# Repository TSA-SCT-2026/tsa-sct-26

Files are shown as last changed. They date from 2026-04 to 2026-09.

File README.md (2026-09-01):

# LEGO Brick Sorter

An ESP32-controlled conveyor that identifies red and blue 2x2 and 2x3 LEGO
bricks, then routes them into four bins with a servo-driven rotary chute. I
built the machine for the 2026 TSA System Control Technology event.

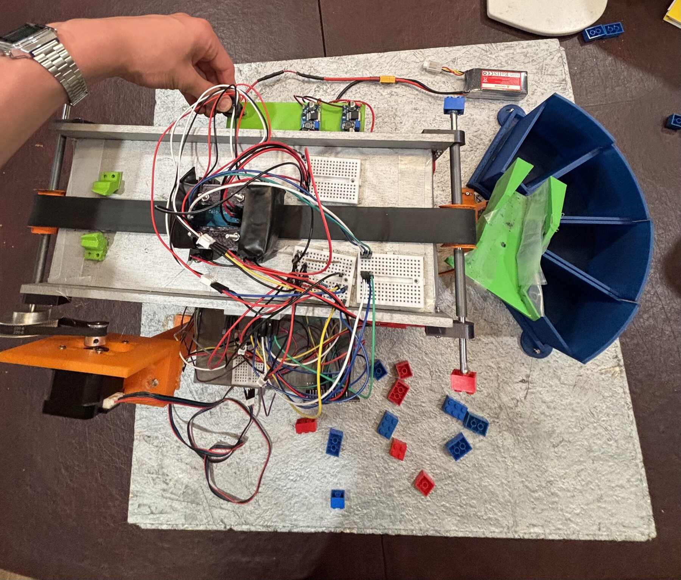
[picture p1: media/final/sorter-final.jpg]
Completed LEGO brick sorter with conveyor, sensing station, rotary chute, and four output bins


Over a roughly one-month, 200-hour development cycle, I worked across the
mechanical design and CAD, power and signal planning, fabrication, firmware,
calibration, and full-system debugging. At its fastest observed operating
point, the completed sorter processed approximately **0.3 bricks/second**, or
**18 bricks/minute**.

## Working demo

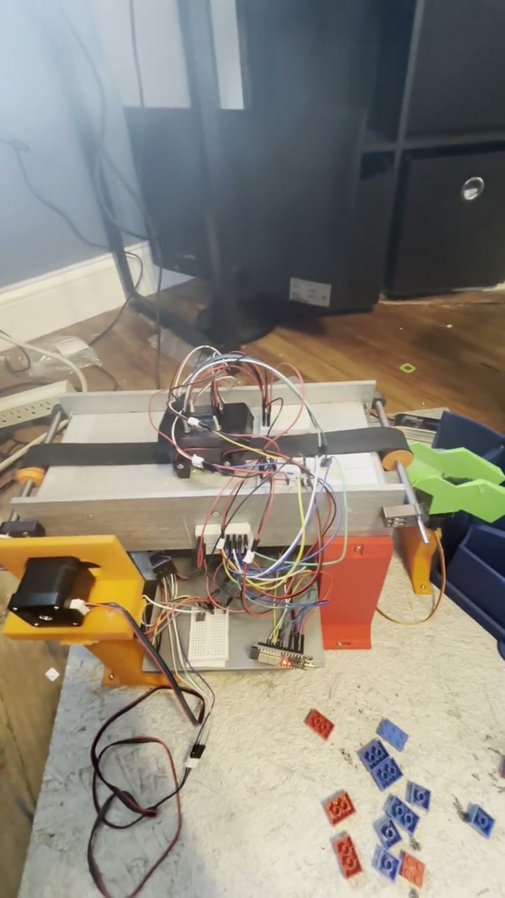
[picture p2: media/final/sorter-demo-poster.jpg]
Watch the completed LEGO brick sorter operate on YouTube


**[Watch the 32-second operating demo on YouTube](https://www.youtube.com/watch?v=zOtNFu6YxYQ).**
The video shows the final conveyor, sensor assembly, rotary chute, and four-bin
layout running as an integrated system.

## System at a glance

A NEMA17 motor drives each brick along the GT2 conveyor and through two break
beams. Between them, a shrouded TCS3200 sensor samples the brick's color. The
ESP32 combines the color reading with timing from the break beams to classify
the brick by size and color, then turns the servo-driven rotary chute toward
the corresponding bin.

- **Mechanics:** dimension-driven conveyor, adjustable sensor mounts, rotary
  chute, and four-bin collection arc
- **Electronics:** ESP32, TMC2209 stepper driver, two break beams, TCS3200 color
  sensor, high-torque servo, fused battery input, and separate voltage rails
- **Firmware:** interrupt-backed edge timing, moving color sampling,
  operator-assisted calibration, NVS persistence, and an event-driven state
  machine
- **Output classes:** 2x2 red, 2x3 red, 2x3 blue, and 2x2 blue

The controller processes one brick at a time across five states: `FEED`,
`SENSING`, `ROUTING`, `HANDOFF`, and `CONFIRM`. It commits the chute position
before the brick reaches the end of the belt.

## Engineering highlights

### Designing from physical constraints

The machine was designed as a connected chain of dimensions rather than a set
of independent parts. Starting with the brick envelope established the usable
belt width and sensing region. Those dimensions constrained the chute mouth and
sweep, which set the bin arc, conveyor height, and the remaining motor,
electronics, and support geometry. Adjustment slots at key interfaces gave the
physical build room for belt tension, print variation, and alignment.

The full dimensional reasoning and build sequence are documented in
[BUILD.md](BUILD.md#constraint-driven-mechanical-design).

### Measuring size as the belt moves

The two break beams are separated by $d = 40.436\ \text{mm}$. Instead of
classifying a brick from a fixed obstruction time, the firmware estimates belt
velocity from each brick's transit between the beams:

$$
v_{\text{lead}} = \frac{d}{t_{B,\text{in}} - t_{A,\text{in}}}
\qquad
v_{\text{trail}} = \frac{d}{t_{B,\text{out}} - t_{A,\text{out}}}
$$

When both estimates are valid, the firmware averages them and converts each
beam's blocked duration into a physical length:

$$
\bar{v} = \frac{v_{\text{lead}} + v_{\text{trail}}}{2}
\qquad
L_A = \bar{v}\left(t_{A,\text{out}} - t_{A,\text{in}}\right)
\qquad
L_B = \bar{v}\left(t_{B,\text{out}} - t_{B,\text{in}}\right)
$$

This keeps the size threshold tied to physical length even as belt tension,
friction, or motor speed changes. The firmware also compares $L_A$ and $L_B$
and handles incomplete or noisy edge sequences explicitly. See the
[full timing and fallback logic](ARCHITECTURE.md#size-measurement) or its
[`sensors.cpp` implementation](firmware/tsa_sorter/sensors.cpp).

### Separating brick color from the moving belt

The TCS3200 cycles through red, blue, and clear filters while a brick crosses
the sensing station. The firmware aggregates multiple samples, subtracts a
captured moving-belt baseline channel by channel, rejects low-signal readings,
and classifies the resulting red/blue relationship.

Calibration is operator-assisted: known bricks establish the working color and
size thresholds, and the selected values and belt baseline are saved in ESP32
NVS. This made it possible to recalibrate the machine without recompiling the
firmware.

### Integrating power, sensing, and control

I sketched the power distribution and signal paths before wiring the machine. A
fuse sits after the battery input, the stepper driver uses the higher-voltage
motor path, and buck conversion supplies the lower-voltage ESP32 and peripheral
rail. The control firmware combines interrupt-time sensor capture with a
64-entry event queue, scheduled chute motion, a single active brick record, and
safe output states for invalid routes or queue overflow.

The [electrical section in BUILD.md](BUILD.md#electrical) includes the original
planning sketches and current firmware pin map. The complete state flow and
failure behavior are in [ARCHITECTURE.md](ARCHITECTURE.md).

## From sketches to a working machine

The first two to three weeks focused on dimensional planning, component
selection, ordering, sketches, and CAD. Fabrication, electronics integration,
firmware, calibration, and debugging came together in a concentrated final
two-week build sprint.

| Frame and rollers | Belt curing and alignment | Electronics integration |
| --- | --- | --- |
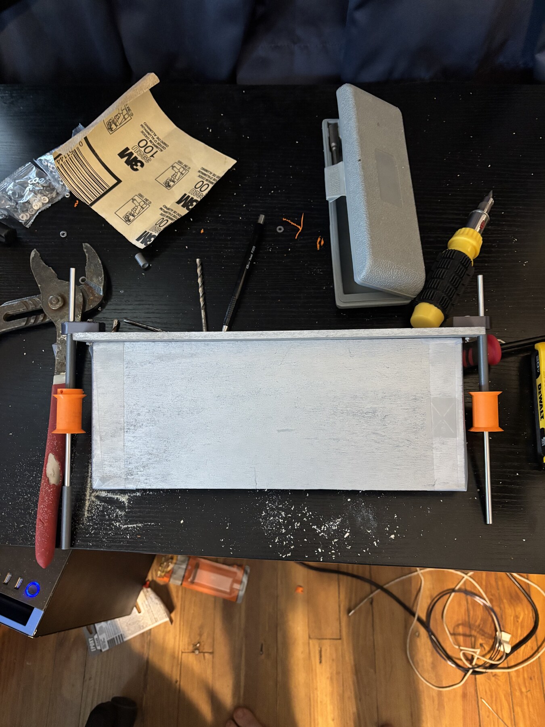
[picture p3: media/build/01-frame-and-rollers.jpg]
Wooden conveyor frame with printed rollers
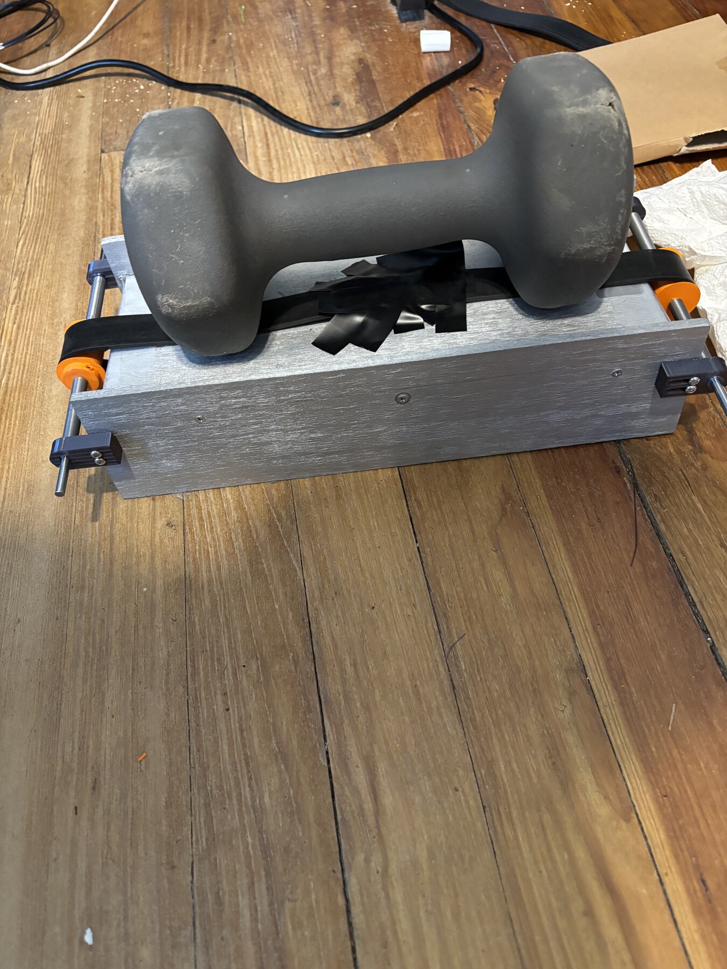
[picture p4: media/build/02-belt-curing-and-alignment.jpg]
Conveyor belt held under weight while epoxy cures
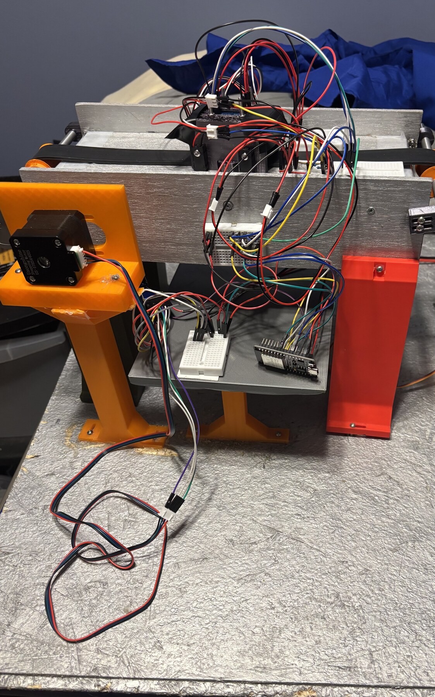
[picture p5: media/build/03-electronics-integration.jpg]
Sorter during electronics integration
|  |  |  |

[See the complete build, wiring, and calibration guide](BUILD.md).

## Explore the project

| Area | Start here |
| --- | --- |
| Firmware and calibration tools | [`firmware/`](firmware/) |
| Control flow and sensing math | [ARCHITECTURE.md](ARCHITECTURE.md) |
| Mechanical build and electrical planning | [BUILD.md](BUILD.md) |
| Conveyor CAD export | [`cad/exports/conveyor-assembly.step`](cad/exports/conveyor-assembly.step) |
| Active-system parts list | [`hardware/BOM.csv`](hardware/BOM.csv) |
| Component references | [`docs/datasheet/`](docs/datasheet/) |

The main firmware is organized by responsibility:

- [`sensors.cpp`](firmware/tsa_sorter/sensors.cpp) — beam timing, TCS3200
  sampling, classification, and calibration data
- [`state_machine.cpp`](firmware/tsa_sorter/state_machine.cpp) — sequential
  feed, sense, route, handoff, and confirmation flow
- [`actuators.cpp`](firmware/tsa_sorter/actuators.cpp) — conveyor profiles,
  servo positioning, and fail-safe outputs
- [`test_harness.cpp`](firmware/tsa_sorter/test_harness.cpp) — serial commands
  for calibration and component testing

## Project role

This was a team TSA project. I am Joe Roche, and I physically built the sorter
while working across its mechanical/CAD, electrical, firmware, calibration, and
integration work.

## License

This repository is available under the [MIT License](LICENSE).

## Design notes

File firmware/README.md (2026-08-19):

# Firmware

PlatformIO firmware for the ESP32-controlled LEGO brick sorter.

## Build

```sh
pio run
pio run -e servo_tuning
```

The default `esp32dev` environment builds `tsa_sorter/`. The
`servo_tuning` environment builds `tools/servo_tuning/main.cpp`.

## Flash and monitor

```sh
pio run -t upload
pio device monitor -b 115200
```

The serial harness supports component checks, human-readable or CSV logging,
operator-assisted calibration, speed-profile selection, and simulated events.
Run `help` in the monitor for the current command list.

Common calibration commands:

```text
cal show
cal belt 8
set color <ratio>
set size <millimeters>
cal save
```

`cal belt` captures a belt baseline. The operator must still choose the color
and size thresholds from physical-run evidence; the firmware does not derive
them automatically.

Use `tools/capture_serial_log.sh` to retain calibration or acceptance evidence.
See [BUILD.md](../BUILD.md) for the full procedure.

## Structure

- `tsa_sorter/`: production controller, sensing, routing, logging, and harness.
- `tools/servo_tuning/`: independent servo-position utility.
- `tools/capture_serial_log.sh`: serial log capture helper.

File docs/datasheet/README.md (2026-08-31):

# Retained Component References

This is a selective extract from the authentic pre-cleanup component library.
It is not a general vendor-download mirror. Each retained file supports a
specific final-system constraint.

| Reference | Constraint it informed |
| --- | --- |
| [`electrical/stepper_driver/images/wiring.png`](electrical/stepper_driver/images/wiring.png) | TMC2209 carrier pin orientation and MS1/MS2 microstep selection. Validate the installed carrier revision before wiring. |
| [`motion/nema17/images/schematic.png`](motion/nema17/images/schematic.png) | NEMA17 mounting pattern, 5 mm shaft, body/shaft envelope, and winding labels used for motor-mount and connector clearance. |
| [`motion/nema17/images/specs.png`](motion/nema17/images/specs.png) | 17HS4401 current, holding-torque, step-angle, and mass reference used to check driver and structure assumptions. |
| [`motion/nema17/cad/stepper_17hs4401s.step`](motion/nema17/cad/stepper_17hs4401s.step) | Reference envelope for the conveyor motor mount; it is supplier geometry, not project-authored CAD. |
| [`fasteners/bearing/cad/nsk_mr85zz.stp`](fasteners/bearing/cad/nsk_mr85zz.stp) | MR85ZZ bearing envelope used for shaft-support and pocket-fit checks. |
| [`reference/lego_2x3/lego2x3_red.stp`](reference/lego_2x3/lego2x3_red.stp) and [`reference/lego_2x3/lego2x3_red.txt`](reference/lego_2x3/lego2x3_red.txt) | Longest supported brick envelope used for guide, shroud, and chute clearance. |
| [`sensing/color_sensor/datasheets/gy31_color_module.pdf`](sensing/color_sensor/datasheets/gy31_color_module.pdf) | GY-31 module pinout, 2.7-5.5 V range, LED control, and 33.2 x 33.2 x 25 mm module envelope. |
| [`sensing/color_sensor/datasheets/tcs230.pdf`](sensing/color_sensor/datasheets/tcs230.pdf) | TCS230/TCS3200-family filter selection, output-frequency scaling, pulse-output behavior, and electrical limits behind firmware sampling. |

## Deliberate exclusions

- Generic product photos, branded
  belt/pulley vendor models are excluded because the system-level conveyor STEP
  already carries the useful assembled geometry. Other parts, such as the IR break beams, may require modifications to CAD depending on size. Cross check parts to order with CAD models.

These files remain third-party references. Their presence does not imply
project authorship or grant redistribution rights beyond their original terms.

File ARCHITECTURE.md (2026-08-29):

# Architecture

The sorter is a sequential, event-driven ESP32 system. It accepts one brick,
measures it inside a shrouded station, positions a rotary chute, and waits for
the timed handoff before accepting the next brick.

## Physical path

```text
feed guide
  -> GT2 conveyor
  -> beam A
  -> TCS3200 color sampling region
  -> beam B
  -> belt exit
  -> servo rotary chute
  -> four bins
```

The configured event set contains red and blue 2x2 and 2x3 bricks. Bricks are
fed studs up, with their long axis aligned to conveyor travel. The current
firmware owns one brick record at a time; physical spacing must prevent a second
brick from entering the sensing window before the controller returns to `FEED`.

## Firmware layers

| Area | Responsibility |
| --- | --- |
| `main.cpp` | Safe startup pin states, subsystem initialization, event dispatch |
| `sensors.cpp` | Interrupt-backed beam timing, color sampling, classification, calibration state |
| `state_machine.cpp` | Sequential feed, sense, route, handoff, confirm, complete, and error states |
| `actuators.cpp` | Stepper PWM, conveyor speed profiles, servo positioning, buzzer, status logging |
| `events.cpp` | Fixed-capacity event queue shared by hardware and the serial harness |
| `logger.cpp` | Human-readable and CSV serial evidence |
| `test_harness.cpp` | Serial commands for calibration, component checks, and simulated events |
| `tuning_profile.h` | ESP32 NVS persistence for operator-selected calibration values |

## State flow

```text
IDLE -> FEED -> SENSING -> ROUTING -> HANDOFF -> CONFIRM
          ^                                      |
          |                                      v
          +------------- next brick --------- FEED

COMPLETE is declared but is not reached automatically in the current path
on protected failure: ERROR_HALT
```

After a startup delay, the firmware starts a run automatically. There is no
physical start-button path in the current implementation. Beam A normally
opens the sensing cycle; beam B can provide a fallback entry trigger if beam A
is missed. Interrupt service routines retain the edge timestamps while the
64-entry event queue decouples input capture from state transitions.

## Size measurement

Let the active center-to-center beam spacing be $d$ (40.436 mm by default),
and define entry/exit timestamps from the active-low beam transitions. The
implemented estimates are:

$$
\Delta t_{lead}=t_{B,in}-t_{A,in},\quad
\Delta t_{trail}=t_{B,out}-t_{A,out}
$$

$$
v_{lead}=\frac{d}{\Delta t_{lead}},\quad
v_{trail}=\frac{d}{\Delta t_{trail}},\quad
v_{avg}=\frac{v_{lead}+v_{trail}}{2}
$$

When only a positive leading-edge delta is available, `v_avg` uses `v_lead`.
If no dynamic estimate is available, length calculation uses the configured
230 mm/s fallback. Beam occlusion durations
$\tau_A=t_{A,out}-t_{A,in}$ and
$\tau_B=t_{B,out}-t_{B,in}$ produce:

$$
L_A=v\tau_A,\qquad L_B=v\tau_B
$$

With both valid measurements, firmware averages the lengths when Beam A has at
most one extra edge, Beam B has at most two, and both speed and length skew are
at most 40%. Otherwise it prefers the beam with fewer extra transitions; on an
equal-edge high-skew result it conservatively chooses the larger length. A
single valid occlusion can supply a provisional length, but size classification
is marked valid only when Beam B entry and exit timing are complete. This keeps
the millimeter threshold responsive to measured belt motion while rejecting an
incomplete two-beam pass as a confident result.

## Color measurement

The TCS3200 is switched through red, blue, and clear filters during a pass. Each
filter frequency is derived from up to four valid pulse periods. During beam
transit the controller attempts a color sample every 70 ms; invalid pulse
periods are discarded. If the operator has captured a belt baseline, its
average red, blue, and clear frequencies are subtracted channel-by-channel and
clamped at zero before the sample is retained. The kept net channels are then
averaged across the pass and produce:

```text
red_ratio = red_net / (red_net + blue_net)
```

At least three belt-separated pass samples are required for a normal result.
Low-signal samples are rejected; if too few remain, the highest-signal rejected
sample is retained as an explicitly best-effort reading. The ratio is compared
with the operator-selected threshold. Current comments record repeated moving
known-brick clusters near 0.467 for blue and 0.512 for red, with a configured
0.490 threshold.

## Operator-assisted calibration

The software does not derive new thresholds automatically. An operator:

1. captures a belt baseline,
2. records representative red/blue and 2x2/2x3 passes,
3. chooses separating color and size thresholds,
4. enters those values over serial, and
5. saves the profile to NVS.

The saved profile contains the color threshold, size threshold, beam spacing,
and averaged belt readings. Defaults in `config.h` remain the recovery path.

## Routing and confirmation

The category-to-bin mapping selects one of four calibrated servo angles. The
controller estimates travel from the sensing station to the chute and tries to
position the chute before the brick commits to the exit. Conveyor speed can be
reduced when the available routing window is tight.

The current path is deliberately sequential: `_token` guards one active
`BrickRecord`, and the next record is created only after timed confirmation.
Events that do not match the current state are ignored; therefore the firmware
does not safely track a second physical brick entering the sensing window while
the first is routing. The serial `in_flight` diagnostic is retained for log
compatibility and is always `0`.

Confirmation is time-based. After the estimated handoff and confirmation
windows, firmware records the commanded bin; no per-bin sensor independently
confirms the landing.

## Active protection and failure behavior

- Startup clamps the active-low conveyor driver off before rail-settling delays.
- Servo and stepper PWM use isolated ESP32 timer/channel allocation.
- Event-queue overflow, an invalid servo route, or an internal token re-entry
  violation stops the conveyor, holds the selector, sounds the buzzer, logs the
  error, and enters `ERROR_HALT` until reset.
- Beam capture has a 3.5-second deadline. Incomplete timing becomes an uncertain
  result rather than an infinite wait; the state machine marks any forced route
  as low-confidence/guessed.
- Extra beam transitions plus speed/length skew determine whether two length
  estimates are averaged, one beam is preferred, or the larger estimate is
  used.
- Thresholds, pin assignments, timing constants, speed profiles, and servo
  angles are hardware-sensitive and should not change without a physical test.

Declared error names for feed timeout, sensor fault, position drift, and missed
bin remain in the interface, but the current physical path does not emit all of
them. Feed timeout presently logs and continues waiting, sensing retry is
compiled with a limit of zero, and no independent bin beam is installed.

## Implementation limits

- Status-display functions currently log over serial rather than driving a
  connected display.
- Timed confirmation records the commanded bin; it is not physical landing
  verification.
- `S_COMPLETE` exists, but the current confirmation path starts another brick
  instead of automatically ending after `TOTAL_BRICKS`; runs require operator
  control to stop at the intended set size.
- Low-confidence `chooseBestGuessBin()` routing currently maps 2x3 red to bin 4
  and 2x2 blue to bin 2; the normal confident category mapping is correct.
- The repository includes the pre-build wiring sketches and firmware pin map,
  but not a full as-built wiring schematic.

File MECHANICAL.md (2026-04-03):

# Mechanical Design Architecture

## Brick dimensions (source of truth)

| Brick | Length | Width | Height | Count | Colors |
|---|---|---|---|---|---|
| 2x2 | 15.8mm | 15.8mm | 11.4mm | 12 | 6 red, 6 blue |
| 2x3 | 23.7mm | 15.8mm | 11.4mm | 12 | 4 red, 8 blue |

Both bricks share the same width and height. Only length differs by 7.9mm. This single fact drives most mechanical and sensor decisions in the project.

## Physical constants

```
Belt width:              25mm
Belt type:               GT2 closed loop, 400mm, 6mm wide
Pulley teeth:            20
Pulley pitch diameter:   12.73mm (20 * 2mm pitch / pi)
Pulley center-to-center: 180mm
Belt speed (operating):  200mm/s
Brick spacing:           28mm center-to-center (23.7mm brick + 4.3mm buffer)
Feed rate:               5 bricks per second
Total sort time:         ~10 seconds for 24 bricks
Footprint:               610mm x 610mm
Materials:               3D printed PLA for all structural parts, fasteners and electronics excepted
```

Belt length math:
```
GT2 20-tooth pulley pitch diameter = 12.73mm
Belt wrap contribution = pi * 12.73 = 39.96mm, rounds to 40mm
400mm belt -> center distance = (400 - 40) / 2 = 180mm
```

System belt usage:
```
Chute base transition:       50mm
Taper channel:               60mm
Sensing zone:                30mm
Sensor to first plow buffer: 30mm
3 plows at ~28mm each:       84mm
Last plow to belt end:       20mm
Total belt needed:           274mm
Belt usable top run:         ~360mm
Margin:                      ~86mm
```

## Parts to print (in order)

1. Chute transition piece -- print and test first, before anything else
2. Stepper cam disk -- simple geometry, early iteration is cheap
3. Sensor shroud for color sensor -- needed for calibration validation
4. Everything else once the chute transition is proven

Do not print the full frame until the chute transition piece reliably feeds bricks at belt speed. That piece is the gate for the entire mechanical build.

## Gravity chute

Near-vertical stack angle: ~75 degrees from horizontal. Bricks orient studs-up for low contact area and minimal friction. Gravity feeds them down into the escapement.

```
Chute inner width:  17.3mm (15.8mm brick + 1.5mm clearance)
Stack height (all 2x3): 24 * 11.4mm = 273mm
Realistic mixed stack:  ~240mm
```

The inner profile must be rectangular to maintain brick orientation. Round pipe cannot constrain rotation -- PVC pipe is not a viable substitute. Aluminum square tube would be dimensionally more accurate than printed PLA but adds sourcing complexity and is harder to integrate with the printed frame. Printed PLA is the correct choice with proper tolerance allowance.

A brick loaded sideways jams at the chute entrance rather than deep in the system. This is the correct failure mode -- visible, immediate, and recoverable.

### Chute transition piece (highest risk item in the project)

The transition from near-vertical to horizontal at the chute base is a compound geometry problem. FDM tolerances bite hard on curved internal profiles. This piece must:
- Redirect bricks smoothly from ~75 degrees to horizontal
- Not allow bricks to tumble, jam, or stack at the curve
- Work reliably at the escapement release rate with bricks of both lengths

Print this first. Test with real bricks. Iterate until it works every time. Budget 3 iterations minimum. Do not proceed to full frame CAD until this passes. If this piece cannot be made to work reliably, the entire near-vertical chute concept needs revision before anything else is built.

## Stepper cam escapement

Single-lobe cam disk mounted on the stepper motor shaft. One full rotation releases exactly one brick and blocks the queue for the remainder of the rotation. This is mechanically guaranteed -- it cannot release a partial brick.

```
Approximate lobe dimensions: 12mm height, 15mm width
One full rotation = 200 steps (1.8 degrees per step)
Release portion = ~50 steps (90 degrees)
At target speed: 30ms per release
```

The cam disk geometry does not require a reference CAD model. A single-lobe disk is trivial to draw from these dimensions -- a circle with one raised protrusion. The lobe pushes the bottom brick onto the belt as it passes; the rest of the disk holds the queue. Iterate the lobe profile with real bricks if the first print does not push cleanly.

The stepper holds its position electrically between releases using reduced current. This means the queue cannot backdrive the escapement when the motor is stationary.

## Taper channel

```
Entrance width: 30mm
Exit width:     17.3mm
Taper length:   60mm
Position:       between chute exit and sensing zone
```

Forces bricks square before sensors and plows. A severely yawed brick jams here, not at the plow. Better failure mode.

## Sensing zone

```
Total zone length:     ~30mm
IR break-beam spacing: 19mm (along travel axis)
Color sensor standoff: 5-10mm above belt surface
```

The color sensor shroud is part of the channel roof geometry -- print it as one piece with the channel. Ambient light is the primary failure mode for the color sensor. The shroud must block all light except the sensor's integrated LED.

### Shroud design requirements

The shroud is not just a box around the sensor. It needs to:

1. Seal against the belt surface (or come very close) on the leading and trailing edges so ambient light cannot enter from the direction of travel. A gap of even 2-3mm at the belt surface at this standoff distance leaks enough light to shift color readings.
2. Allow bricks to enter and exit freely without snagging. The opening should be wider than the brick but use a labyrinth or overlapping lip geometry to block direct light paths rather than a simple open slot.
3. Have a flat ceiling at a consistent standoff distance (5-10mm). Variation in standoff distance across the brick changes the integrated light level and potentially the ratio. Consistent geometry matters.
4. Be CAD'd with the color sensor dimensions in mind -- mount the sensor board flush against the shroud ceiling, not floating inside it.

This piece needs to be iterated. Print it early, test it with a handheld flashlight pointed at the belt from various angles while the sensor is logging readings. If the ratio shifts when ambient light changes, the shroud is not tight enough.

### Brick orientation enforcement at chute entrance

The chute width (17.3mm) already prevents 2x3 bricks from entering rotated 90 degrees -- 23.7mm does not fit in 17.3mm. A 2x2 is square so rotation does not matter for it. Studs up vs studs down does not affect size or color measurements.

The remaining risk is a brick loaded completely on its side (11.4mm height presenting instead of 15.8mm length). Make the chute entrance opening narrow enough in the vertical dimension to prevent this. If a brick cannot enter on its side at the top of the chute, this failure mode is eliminated before it can cause a jam or misclassification.

## Plow diverters

Three plows, Class 3 lever geometry, solenoid actuated, spring return.

Lever geometry:
```
Pivot to solenoid attachment: 8mm (L1)
Pivot to plow tip:            24mm (L2)
Mechanical advantage ratio:   3.0
Solenoid stroke:              10mm
Tip travel:                   30mm (adequate to clear 15.8mm brick width on 25mm belt)
```

Tip travel needed calculation:
```
(belt width / 2) + (brick width / 2) + buffer = 12.5 + 7.9 + 4 = 24.4mm -> use 30mm
```

The solenoid connects to the lever arm via a pinned connection (M2 pin through a drilled hole or small clevis). Not a hook or slot -- a pinned connection eliminates rattle, wear, and angular play at speed.

A slot in the channel wall accommodates the arc the solenoid rod travels. At these angles the arc is nearly linear -- this is not a fabrication problem.

Chamfer the leading face of each plow arm at 35 degrees. Slightly yawed bricks get nudged square rather than jamming against the face.

### Plow spacing along belt

```
Footprint per plow along belt: ~32mm (lever length + 8mm safety gap)
3 plows total:                 ~96mm
```

### Spring selection

The force margin is large (~94x what the spring requires to return the arm). Use the heaviest spring from the assortment that the solenoid can still reliably overcome -- heavier spring means faster retraction, which is the optimization target. Test with the actual solenoid at operating voltage before committing to a spring weight.

## Bin design

Four bins, one per brick type. Bricks arrive at 200mm/s and will bounce out of empty bins without some form of energy absorption.

Options: foam sheet glued to bin floor, felt lining, or a short downward ramp printed into the bin geometry that redirects kinetic energy downward rather than back toward the belt. The ramp approach is preferable because it is zero-cost (print it into the bin), durable, and does not require gluing or sourcing foam in the right thickness.

## Fastener conventions

- Structural frame joints: M3
- Lever arm pin connections: M2
- Sensor and electronics mounts: M3 preferred
- Pre-order both M2 and M3 hardware kits

## Print tolerances

FDM variance is roughly 0.2mm to 0.5mm. All critical dimensions need explicit tolerance notes in CAD:

- Belt channel width (25mm): ±0.3mm acceptable
- Chute inner width (17.3mm): ±0.2mm, tighter is better, too tight and bricks drag
- Pulley center distance (180mm): tensioner slot provides 5mm of adjustment
- Plow lever arm lengths: ±0.5mm acceptable, ratio is what matters not absolute

Test fit all printed channel sections with real bricks before assembling the full frame.

## Assembly order

1. Chute transition piece validated in isolation
2. Full frame with all channel sections
3. Dry assembly: no wiring, walk a brick through by hand from chute to belt end
4. Fix all print fit issues before wiring anything
5. Wiring and electronics integration
6. First powered test

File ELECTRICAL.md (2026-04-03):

# Electrical Design Architecture

## Power architecture

Two independent power rails from a single 2S LiPo (7.4V, 2000mAh minimum), each stepped down to 5V via a dedicated buck converter.

```
Rail 1: solenoids only (high current, noisy switching)
Rail 2: stepper motor, belt motor, microcontroller, sensors, display (clean logic rail)
Common ground between rails -- only the ground is shared
```

Separating rails keeps solenoid switching noise off the logic rail and stepper driver switching noise off the solenoid rail. Both are real failure modes on a shared rail at this current draw.

### Power budget

```
3 plow solenoids (peak simultaneous): 3 * 500mA = 1500mA
Stepper motor:                        ~400mA
Belt motor:                           ~400mA
Microcontroller:                      ~250mA
Sensors and display:                  ~150mA
Total worst case:                     ~2700mA
Realistic operating peak:             ~1500mA
```

A USB power bank will not work. Most cut out at 1A or less under pulse load. Use LiPo.

Bench supply is acceptable for early development but must not be used for any calibration run that will be logged as performance data, and must not be used for the final demo. Test on LiPo before April 20.

## Component list and electrical specs

| Part | Purpose | Voltage | Peak current |
|---|---|---|---|
| JF-0530B solenoid (x3) | plow actuation | 5V | ~500mA each |
| NEMA 11 stepper motor | escapement | 6-8V (motor rail) | ~400mA |
| A4988 stepper driver | stepper control | motor rail + 3.3V logic | -- |
| TT gearmotor (x2, one spare) | belt drive | 5V | ~400mA |
| L298N motor driver | belt motor control | 5V | -- |
| LM2596 buck converter (x2) | 7.4V -> 5V | -- | 3A each rated |
| ESP32 DevKit | microcontroller | 3.3V (via onboard reg) | ~250mA |
| Adafruit IR break-beam pairs (x6 used) | size and bin sensing | 3.3-5V | low |
| TCS34725 color sensor | color classification | 3.3V | low |
| ST7789 color TFT display | live status display | 3.3V | ~80mA |
| H206 slot optocoupler | belt speed encoder | 3.3-5V | low |
| 2S LiPo 7.4V 2000mAh | main power source | 7.4V nominal | 2A continuous |

## Critical protection components

These are not optional. Skipping any of them risks destroying hardware.

### Capacitor on stepper driver motor power input

A 100uF electrolytic capacitor must be placed physically adjacent to the motor power input on the A4988 driver module. This is the single most common way the A4988 is destroyed -- back-EMF from the motor travels back up the power line on power connect. Without this capacitor, the chip dies. Place it right next to the chip, not at the power connector.

Before applying power to the stepper circuit for the first time: verify this capacitor is present and correctly oriented (negative leg to ground) with a teammate watching. Say it out loud.

### Flyback diodes on all solenoids

Every solenoid must have a flyback diode across its terminals. When the solenoid de-energizes, the collapsing magnetic field generates a large voltage spike. Without a flyback diode, this spike travels back into the microcontroller and will cause brownouts or permanent damage. 1N4007 diodes are sufficient.

Orientation: cathode (banded end) toward the positive supply rail, anode toward the solenoid terminal. A reversed diode is a short circuit.

Verify all three diodes with a multimeter before first solenoid energization.

### Pullup resistors on I2C lines

If the color sensor drops reads during high-speed polling, add 4.7k resistors from SDA and SCL to 3.3V. This is a diagnostic step, not mandatory upfront, but have the resistors available.

## Stepper driver wiring

```
A4988 VMOT + GND  -> motor rail (6-8V from LM2596)
A4988 VDD + GND   -> microcontroller 3.3V, shared ground
A4988 STEP        -> microcontroller GPIO
A4988 DIR         -> microcontroller GPIO (set once at startup)
A4988 SLEEP       -> pull HIGH (enables the driver)
A4988 RESET       -> tie to SLEEP pin
A4988 MS1/MS2/MS3 -> all LOW (full step mode, maximum torque)
A4988 coil pairs  -> NEMA 11 stepper coil wires (check datasheet for coil grouping)
```

VMOT should be 6-8V for the NEMA 11. Do not run from 5V -- insufficient torque at speed. Use the dedicated motor rail from Rail 2.

Between releases, reduce hold current via the driver's reference voltage trim. Sufficient torque to hold against queue pressure, much lower heat. This is done once during setup, not dynamically during normal operation.

## Belt motor wiring

Belt motor connects through the L298N module. The L298N enable pins accept PWM for speed control -- this is how the PI controller adjusts belt speed. No separate speed controller module is needed.

L298N PWM frequency: keep between 1kHz and 10kHz. Below 1kHz the motor audibly ticks. Above 25kHz the L298N's internal circuitry generates excessive heat and switching losses become significant. 5kHz is a reliable starting point.

Motor direction should be wired to run belt surface in the correct direction. Verify this before installing sensors or plows by running a brick manually.

## Bulk capacitor on logic rail

Add a 1000uF electrolytic capacitor between 5V and GND on the logic rail, physically close to the microcontroller. When solenoids fire on Rail 1, even with rail isolation, transients can couple through the common ground. The bulk cap buffers the logic supply during these events and prevents brief undervoltage that could cause a reset.

This is separate from the 100uF cap on the A4988 motor power input -- that one is for the stepper driver, this one is for the microcontroller supply. Both are needed.

## Solenoid control

Each solenoid connects to a microcontroller GPIO through a driver transistor or the L298N. Flyback diode across each solenoid (see above).

Solenoid timing pattern per brick:
- Full power for 15-20ms (full extension)
- Drop to ~40% duty cycle PWM for the remaining hold time (maintains position, roughly half the heat)
- De-energize once the brick has cleared the plow

Brick clears the plow roughly 280ms after the trigger (calculated from brick length, plow footprint, and belt speed). This is the de-energize point. It can be implemented as a fixed timer.

Add a small aluminum heatsink (20x20mm) to each solenoid body using thermal adhesive tape. This is cheap insurance against heat during extended calibration sessions, which will run more solenoid cycles than the competition demo.

## Sensor wiring

### IR break-beams

Each break-beam pair has an emitter and a receiver. The receiver output is a digital signal -- high when beam is intact, low when broken. Wire receivers to microcontroller GPIO pins configured as inputs. The emitter connects to 5V (check Adafruit datasheet for exact supply).

Two pairs for size detection in the sensing zone. One pair per bin entrance, four pairs total for confirmation. Six pairs used, two spare.

### Color sensor

Connects to the microcontroller over I2C. Set the I2C bus clock to 400kHz explicitly in firmware. The default 100kHz is insufficient for the rapid polling rate needed during brick dwell time.

### Display

Connects to the microcontroller over SPI. Runs at 40MHz SPI clock -- verify this is within the display panel's spec (ST7789 supports it). Power at 3.3V.

### Belt speed encoder (if using slotted disk option)

A photointerrupter (H206 or equivalent slot optocoupler) mounts next to the belt pulley. Its output is a digital pulse train -- one pulse per slot as the disk rotates. Wire the output to a GPIO interrupt pin on the microcontroller. Use the ESP32's hardware pulse counter peripheral for counting rather than software interrupts -- it handles high pulse rates without CPU overhead.

The disk can be printed directly into the belt pulley face (add 20 evenly spaced slots around the perimeter). No separate part needed.

## Wiring checklist before first power-on

- [ ] 100uF capacitor adjacent to A4988 motor power input, correctly oriented
- [ ] 1000uF capacitor on logic rail 5V supply, close to microcontroller
- [ ] All three solenoid flyback diodes installed, orientation verified with multimeter
- [ ] Rail 1 and Rail 2 separated, common ground only
- [ ] Both LM2596 outputs measured at 5V before connecting anything
- [ ] Stepper SLEEP pulled HIGH
- [ ] RESET tied to SLEEP
- [ ] Microcontroller powered from clean rail, not motor rail
- [ ] All I2C devices on same bus with shared SDA, SCL, and ground
- [ ] Display SPI connections correct (MOSI, SCLK, CS, DC, RST)
- [ ] Photointerrupter output connected to GPIO interrupt pin (if using slotted disk encoder)

## Common failure modes

| Failure | Cause | Prevention |
|---|---|---|
| A4988 destroyed on power-on | Missing or misplaced 100uF cap | Verify cap before power |
| Microcontroller brownout | Solenoid back-EMF, no flyback diode | Install all flyback diodes |
| Microcontroller brownout | Bench supply current limiting | Test on LiPo |
| Color sensor dropped reads | I2C too slow or noise | Set 400kHz, add pullups if needed |
| Solenoid overheating | Full power hold, no PWM | Implement PWM hold in firmware |
| Belt slipping | Loose belt from print tolerance | Use tensioner slot, re-tension |
| Stepper skipping steps | Insufficient VMOT voltage | Use dedicated motor rail at 6-8V |

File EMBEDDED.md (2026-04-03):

# Embedded Design Architecture

## State machine

```
IDLE -> FEEDING -> SIZE_DETECT -> COLOR_DETECT -> ROUTING -> CONFIRM -> FEEDING
                                                                  |
                                                             ERROR_HALT
```

- IDLE: ready screen on display, button waiting, thermal model cooling down between runs
- FEEDING: stepper fires one full rotation, one brick released onto belt
- SIZE_DETECT: hardware timer running, waiting for second beam break or timeout
- COLOR_DETECT: color sensor averaging samples over brick dwell time
- ROUTING: correct plow fires (or does not fire for default path), display animation triggers
- CONFIRM: waiting for the expected bin beam to break within 500ms
- ERROR_HALT: belt stops, stepper stops, all solenoids de-energize, display shows error with bin and brick number, system waits for reset

Transitions happen on hardware interrupt or timer expiry, not polling loops. The only exception is color sampling during COLOR_DETECT, which samples on a tight loop during the brick's dwell window.

## Size detection

Two IR break-beam pairs in the sensing zone, 19mm apart along the belt axis.

Use hardware timer interrupts -- not software polling, not delay-based measurement. The timer must have at least 1 microsecond resolution. This gives thousands of counts of margin on the 21ms signal window, making misclassification effectively impossible from timing alone.

```
Beam 1 breaks:                timer starts
Beam 2 breaks within timeout: brick is 2x3 (23.7mm long)
Beam 2 times out:             brick is 2x2 (15.8mm long)
```

How the geometry works:
- Beams are 19mm apart. Belt moves at 200mm/s.
- A 2x2 brick is 15.8mm long -- shorter than the 19mm beam gap. Its trailing edge clears beam 1 before its leading edge reaches beam 2. Beam 2 never breaks.
- A 2x3 brick is 23.7mm long -- longer than the gap. Its leading edge reaches beam 2 while the brick is still in beam 1. Time from beam 1 break to beam 2 break: 19mm / 200mm/s = 95ms.
- Timeout should be set above 95ms (use ~150ms). The classification threshold sits anywhere between 0 and 95ms -- 50ms is a reasonable starting point. Validate empirically at actual belt speed during calibration. The margin is large enough that the exact value does not matter much.

## Color detection

Color sensor faces down from the channel roof through a printed shroud, 5-10mm above the belt surface.

I2C bus must be explicitly configured to 400kHz. The default 100kHz is insufficient for the polling rate needed. Set this in initialization code before any sensor communication.

```
Brick dwell time at 200mm/s over 15.8mm: 79ms
Minimum integration time per sample: 2.4ms
Maximum samples per brick: 79 / 2.4 = ~32 samples
```

### Black belt filter

The GT2 belt is black rubber. When the sensor reads bare belt (between bricks, or at brick edges), total raw light across all channels is near zero. Black is trivially easy to detect: if the sum of all raw channels is below a floor threshold, discard the sample.

Set the floor threshold during calibration by logging raw totals for bare belt and brick surface separately. The gap between them will be obvious. This single filter cleanly handles all belt readings without any timing-based windowing logic.

Beam 1 windowing (gate sampling on beam break/restore) can be added as a secondary layer but should not be the primary mechanism. The black filter is simpler and more robust.

### Classification

Average all valid samples within the window. Classify using R / (R + G + B) ratio. Red LEGO bricks have a strong spectral signature and will produce a clearly high ratio. Blue LEGO bricks will produce a clearly low ratio. The gap between them is large -- this is one of the easier color classification problems you can choose. The risk is not in the classification math, it is in the windowing and shroud (see MECHANICAL.md for shroud design notes).

The exact threshold (nominally ~0.45) must be calibrated empirically with the shroud installed, demo bricks, belt running, integrated LED as the only light source. Log raw R/G/B values for both brick colors during calibration to understand the actual separation. Do not assume any threshold value.

### Tuning methodology

During calibration, run both brick colors at multiple belt speeds and log raw channel values for each sample. Determine:
- The actual ratio distributions for red vs blue at your operating speed
- The optimal threshold (midpoint between distributions, or weighted toward the more common misclassification direction)
- The minimum number of samples needed for reliable classification

This produces documentation data and a principled threshold choice.

## Routing logic

Routing is a direct lookup from classification result to plow assignment. Optimized by brick frequency so the most common brick type fires no solenoid.

```
2x3 blue (8/24): no solenoid fires -- default path, brick reaches end bin
2x2 blue (6/24): plow 1 fires
2x2 red  (6/24): plow 2 fires
2x3 red  (4/24): plow 3 fires
```

One plow fires per brick, maximum. Total solenoid fires per full run: 16.

Solenoid fires immediately when classification completes. The brick is still traveling from the sensing zone to the first plow -- roughly 150ms of travel time at 200mm/s over 30mm. Solenoid actuation takes 10ms. The plow is pre-set before the brick arrives.

PWM hold timing per solenoid:
- Full power for the first 20ms (full extension reached)
- Drop to ~40% PWM duty cycle (maintains position, reduced heat)
- De-energize at approximately 280ms after trigger (brick has cleared the plow)

This is implemented as a timer-based state transition in firmware. The de-energize time can be calculated at the start of each routing event.

## Bin confirmation

Four break-beams, one at each bin entrance. After a brick is routed, start a 500ms countdown for the expected bin beam.

On beam break within window: log success, increment bin counter, trigger display update, transition back to FEEDING.
On timeout: transition to ERROR_HALT.

GPIO interrupt priority: size detection beams are highest priority. Bin confirmation beams are lower priority. Do not allow a bin confirmation interrupt to delay a size detection measurement.

## Thermal model

Runs continuously. Tracks accumulated heat for each actuator independently. Heat increases when an actuator fires. Heat decays exponentially over time when idle.

```
On actuator fire:    heat += duration * heat_per_unit_time
Each update cycle:   heat *= cooling_factor ^ elapsed_seconds
```

Two thresholds:
- WARNING: reduce stepper release rate slightly (increase gap between bricks)
- DANGER: reduce stepper release rate significantly

The model protects hardware during back-to-back demo runs, not just a single run. Between runs, while in IDLE, the model continues to update and heat values decay. The display shows the thermal state as a small bar throughout.

Apply the model to all solenoids and the stepper motor. The belt motor does not need it.

## Belt speed control (PI controller)

Belt speed is a tunable parameter. Optimal speed balances throughput against classification accuracy. Too fast: color samples compress, size timing margins shrink, bricks may jam the taper. Too slow: run takes longer than needed.

### Three speed measurement options

**Option A: Reuse size detection break-beams (no extra hardware)**
- 2x3 bricks: time from beam 1 to beam 2 break = 19mm / speed
- 2x2 bricks: duration beam 1 is blocked = 15.8mm / speed
- Every brick gives a speed sample (~5 per second)
- Update rate is limited but workable for a slow process variable like belt speed

**Option B: Bin confirmation transit time (no extra hardware, already happening)**
- When a brick is routed, log the timestamp. When the bin confirmation beam breaks, log another.
- Speed = known sensor-to-bin distance / elapsed time
- Every brick gives a speed measurement, all 24 bricks per run
- Downside: measurement is trailing -- informs the next brick, not the current one
- Each bin is at a different distance from the sensor zone, so you need exact CAD measurements for all 4 paths (determine in dry assembly, not estimated)

**Option C: Slotted disk on belt pulley with photointerrupter (recommended, ~$1 extra)**
A printed disk with radial slots mounts on the belt pulley shaft. A U-shaped light sensor (photointerrupter/optocoupler) straddles the disk edge. As the pulley spins, slots pass through the sensor gap and generate pulses. Count pulses per unit time = rotation speed = belt speed.

At 200mm/s: pulley does ~5 rotations/sec. A 20-slot disk gives 100 pulses/sec -- one pulse every 10ms. This is continuous real-time feedback at high bandwidth, genuinely good for a PI controller. The disk can be printed directly as an extension of the belt pulley face. Requires adding one H206 slot sensor to the BOM (~$1).

This is the cleanest option. Use A or B for validation and logging. Use C for the actual PI controller if added.

### Tuning methodology

Run the full 24-brick set at multiple belt speeds (e.g., 100, 150, 200, 250mm/s). Log all per-brick classification results and confirmation outcomes. Identify:
- Minimum speed for reliable color classification
- Maximum speed before size detection degrades
- The accuracy vs speed curve

Set operational setpoint to the fastest speed that holds target accuracy (95%+). This generates strong documentation data and a principled, equation-backed design choice.

### PI controller notes

Start with proportional control only. Add integral if steady-state offset persists. Derivative not needed -- belt speed is slow and smooth. Gains will be small. The controller update rate is determined by whichever speed measurement option you use.

### Development tool: web server logging

The ESP32 has WiFi. During calibration and tuning, run a lightweight HTTP server that serves a live JSON feed of brick events, speed measurements, and classification results. Connect a laptop to the same network and log directly in the browser or with a simple script. This is faster and more convenient than serial + CSV piping for iterative tuning sessions. Disable or make it optional in competition firmware (adds latency).

## Display

Color TFT over SPI. All display updates happen asynchronously relative to the sensing and routing pipeline -- they must not block or delay state transitions.

During sort (triggered on ROUTING state entry, not on physical bin arrival):
- Brick silhouette animates down the chute graphic in the correct classification color (red or blue) and correct aspect ratio (2x2 or 2x3)
- Bin counter for the target bin flashes then increments
- Sidebar shows brick number, size, color, destination bin
- Thermal bar updates

Render bricks as small pre-rendered bitmaps stored in flash memory. Clear the background rectangle, redraw the bitmap -- no full-screen refresh needed. Animation should complete within 150ms to avoid queuing at 5 bricks per second.

RGB565 color format: red is 0xF800, blue is 0x001F. These are exact matches for LEGO red and blue under normal conditions.

End screen (triggered when all 24 bricks confirmed):
- SORT COMPLETE header
- Total run time
- Per-bin totals vs expected (6, 6, 4, 8)
- Count of missed confirmations if any
- Green indicator if all counts match, yellow if discrepancy

## Serial output

Log every event with a millisecond timestamp:
- Each brick: number, size classification, color classification, destination bin
- Each bin confirmation: timestamp, which bin, success or timeout
- End of run: all totals, total time
- Thermal model state periodically

Serial output is the engineering notebook. Pipe it to a laptop during calibration and save to CSV. Performance test data, belt speed validation (compare expected vs measured transit times), and accuracy rates all come from this log. Do not manually record runs.

The time between ROUTING timestamp and CONFIRM timestamp gives measured transit time, which divided into the sensor-to-bin distance gives measured belt speed. This is a sanity check on the belt speed calculation. Log it. Judges appreciate a system that validates its own performance claims.

## Button and start/stop

Momentary button, wired to a GPIO with internal pullup. Press starts a run from IDLE. The competition rules require a manual start/stop -- do not auto-run on power-up.

Optional: a second button for slow demo mode (half belt speed, exaggerated animation timing). Costs nothing in firmware. Useful during judging explanations.

## Firmware checklist

State machine:
- [ ] All states and transitions implemented
- [ ] ERROR_HALT stops belt, stepper, and all solenoids
- [ ] Manual button triggers IDLE -> FEEDING
- [ ] End-of-run count verification against expected (6, 6, 4, 8)

Sensing:
- [ ] Hardware timer interrupt for size detection (1us or better resolution)
- [ ] I2C clock explicitly set to 400kHz before first sensor read
- [ ] Color sensor: N-sample averaging over dwell window
- [ ] Color ratio classifier with empirical threshold
- [ ] Size threshold validated empirically during calibration
- [ ] GPIO interrupt priority: size beams > bin confirmation beams

Actuation:
- [ ] Stepper: step and direction control, full rotation per release
- [ ] Stepper: reduced hold current between releases
- [ ] Solenoid: PWM drop to 40% duty cycle after 20ms full extension
- [ ] Solenoid: de-energize at calculated brick-cleared time (~280ms)
- [ ] Solenoid: all flyback diodes confirmed in hardware before first energization
- [ ] Bin confirmation: 500ms timeout, ERROR_HALT on miss

Thermal:
- [ ] Exponential decay model for all solenoids and stepper
- [ ] WARNING threshold: reduce release rate
- [ ] DANGER threshold: reduce release rate further
- [ ] Thermal state displayed on screen

Display:
- [ ] Color TFT driver initialized over SPI
- [ ] Ready screen on IDLE entry
- [ ] Brick animation: correct color, correct aspect ratio, triggers on ROUTING
- [ ] Bin counter flash and increment
- [ ] Thermal bar on sidebar
- [ ] End screen: run time, per-bin totals, accuracy

Logging:
- [ ] Serial timestamp on every significant event
- [ ] Per-brick log: number, size, color, bin, confirmation result
- [ ] End-of-run summary log
- [ ] Belt speed validation from transit time logs

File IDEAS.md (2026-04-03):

# Ideas and Design Exploration

Scratchpad for concepts that are exploratory, not yet architecture. Some of these informed current design decisions. Some may still be relevant if a subsystem needs to be reconsidered.

---

## Alternative diverter mechanisms (considered before committing to solenoid plow)

Every design was evaluated against the core constraint: sort 5 bricks per second, 200mm/s belt, 140ms inter-brick window.

**Solenoid plow -- current design**
Pre-set before brick arrives, actuation off critical path, spring return is passive. The only mechanism that fully decouples actuation timing from belt speed. Chosen.

**Servo flap**
Weakness: 100-150ms sweep and return time. Eats the entire inter-brick window. Throughput drops to 2-3 bricks/second. Not viable at target speed.

**Solenoid puller / fast retractor**
Instead of pushing the arm out and spring-returning it, the solenoid holds the arm retracted (in the normal/clear position) and releases it to snap forward under spring power, then re-energizes to retract again. The spring does the divert, not the solenoid. This could be fast -- spring snap is faster than solenoid pull. However it means the solenoid is energized most of the time (holding retracted), inverting the heat profile. Current design has solenoids de-energized by default, which is thermally better for 33% of bricks that take the default path with zero actuation. Puller concept is interesting but thermal trade-off goes the wrong direction for this brick distribution.

**Paddle wheel / continuous rotation**
Weakness: timing is mechanically coupled to belt speed, requires synchronization. One paddle per bin path, significant footprint. No selective control without a clutch. See ARCHITECTURE.md for full analysis.

**Pop-up gate (pin through belt)**
Weakness: GT2 belt cannot be slotted without structural failure. Requires a second mechanism to clear the brick. Physically stops bricks rather than deflecting them, which means bounce and jam risk.

**Track diverter (physical rail switches)**
Weakness: inertia cost on both brick and mechanism. Like a pop-up gate but larger footprint. Mechanically interesting but slower than solenoid plow.

**Conveyor -> solenoid queued tilting platform**
A short platform between belt segments that tilts to route the brick to one side. Weakness: cost of inertia (needs a lip to slow brick down before tilt), gravity-friction speed limits return, more moving mass than a plow arm. Complex to mount at belt speed.

**Diagonal conveyors that reverse to collect**
Multiple belts at angles to the main belt that can redirect by reversing direction. Weakness: inertia at belt transitions, potentially the fastest if conveyors run extremely fast, but the transition inertia cost may exceed what is saved. Footprint and complexity are significant. Worth researching if current design hits a throughput wall -- specifically look at conveyor speed vs inertia cost equations before dismissing.

**Omnidirectional ball / pop-up perpendicular conveyor**
An omnidirectional wheel or roller array that activates to push bricks sideways off the main belt. Weakness: inertia, requires brick to be nearly stationary or moving slowly relative to the crossbelt. Not viable at 200mm/s on a 2ft platform.

---

## Puller vs pusher solenoid timing optimization

For any solenoid-actuated mechanism, consider which direction the solenoid pushes vs which direction is spring-loaded. The puller variant: spring loads the active position, solenoid holds the neutral position. This means the active movement is instant (spring snap) rather than solenoid-speed. Retraction is solenoid-speed rather than spring-speed.

For our plow: the spring returns the arm to the clear position (neutral). The solenoid pushes to the divert position. This means divert motion is solenoid speed (~10ms), clear motion is spring speed (15-20ms target). The divert is on the critical path (needs to happen before brick arrives). The clear is not critical (brick has already passed). Current design is already optimized: fast direction = solenoid, return direction = spring.

If a future design needs faster return (spring) and slower extension (solenoid), invert the geometry.

---

## Engineering notebook as a decision driver

The notebook should guide decisions, not just record them. Every significant design choice should be preceded by: define the constraints, list the options, derive the winning option mathematically from the constraints. The notebook documents that derivation, not just the conclusion.

Judges should be able to trace every dimension, every threshold, every timing value back to an equation with variables and constants written out. If you changed a value, the notebook explains why -- what measurement or data caused the revision.

Charts for everything: speed vs accuracy curve, lever geometry diagram, timing diagram for the sensing zone, power budget table, thermal model decay curve. Equations in the margin. Constants labeled.

---

## Wall power vs battery

For calibration sessions, a bench supply is more stable than LiPo. However it must never be used for logged runs or demo.

If the competition venue allows a wall outlet, a 5V 3A regulated wall adapter would be more stable than LiPo for demo. TSA competitions typically do not guarantee outlet access at the judging table. Assume battery only for competition.

The bulk capacitor on the logic rail (1000uF, see ELECTRICAL.md) partially addresses supply stability by buffering transients regardless of power source.

---

## Possible additions if time permits

These are lower priority and should only be attempted after the core system is reliable and all 10 reliability runs are logged.

- **PI speed controller** (fully detailed in EMBEDDED.md): closed-loop belt speed using slotted disk encoder
- **Web server logging** (in EMBEDDED.md): live JSON event feed over WiFi during calibration
- **Slow demo mode**: second button halves belt speed and slows animations -- useful during judge explanations
- **Brick counter on display**: large text showing bricks sorted out of 24, visible from across the table
- **Break-beam at chute exit**: confirms escapement fired and brick left the chute before entering the sensing zone, one more feedback point

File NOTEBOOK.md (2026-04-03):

# Engineering Notebook

The notebook is the primary scoring artifact alongside the live demo. Judges use it to evaluate the quality of engineering thinking, not just the final design. It must show that decisions were derived from math and data, not assumed or copied.

Every entry in this notebook should follow the same pattern:
1. What question were we answering?
2. What did we measure or calculate?
3. What decision did it produce?
4. What did we test to validate?

The notebook guides decisions. It does not just record them after the fact.

Scoring: Inventor's Log is 20 of 100 points. It is evaluated by judges reading it without the team present. It must stand alone.

---

## Required sections (checklist)

### Design decisions (derive from equations, not intuition)

- [ ] Size sensor selection -- IR break-beam vs ultrasonic vs ToF vs camera
  - Key equation: noise floor of each option vs brick length difference (7.9mm)
  - Include measurement specs for each sensor type considered

- [ ] Color sensor selection -- TCS34725 vs camera vs discrete photodiodes
  - Key equation: dwell time at operating speed vs minimum integration time required per sensor type

- [ ] Plow actuation -- solenoid vs servo vs paddle wheel vs pop-up gate
  - Key equation: actuation time needed vs inter-brick window at target throughput (140ms at 5 bricks/s)

- [ ] Escapement mechanism -- stepper cam vs dual-pin solenoid vs Geneva drive vs rotary servo
  - Key constraint: sustained duty cycle at 5 bricks/s over multiple consecutive runs
  - Thermal analysis for each option

### Equations (write out with all variables and constants labeled)

- [ ] Lever geometry: L1, L2, ratio, solenoid stroke, tip travel derivation
- [ ] Belt sizing: pulley pitch diameter, center-to-center distance, total belt length
- [ ] Brick spacing: maximum brick length + buffer -> center-to-center gap -> inter-brick window
- [ ] Dwell time: belt speed, brick width, samples per brick
- [ ] Size detection timing: beam spacing, belt speed, expected gap for 2x3, timeout for 2x2
- [ ] Solenoid de-energize timing: brick length + plow footprint, belt speed -> on-time calculation
- [ ] Thermal model: heat accumulation rate, exponential decay constant, threshold derivations
- [ ] Power budget: all components, peak simultaneous draw, LiPo capacity vs run count
- [ ] Throughput: stepper cycle time, belt speed, brick spacing -> bricks per second

### Charts (every major parameter gets a chart)

- [ ] Accuracy vs belt speed (from calibration sweep data)
- [ ] Speed vs time (PI controller behavior during a run)
- [ ] Color ratio distribution: red and blue brick readings plotted, threshold shown
- [ ] Thermal state over time during back-to-back runs
- [ ] Per-bin accuracy over 10+ runs (bar chart, expected vs actual)

### Calibration records

- [ ] Color sensor: raw R/G/B readings for both brick colors under shroud LED, belt running
- [ ] Color sensor: floor threshold for belt surface black filter (bare belt total light reading)
- [ ] Size detection: actual beam-to-beam timing measured for 2x3 bricks at operating speed
- [ ] Size detection: confirmed 2x2 never reaches beam 2 (confirmed timeout behavior)
- [ ] Belt speed: actual speed at target PWM duty cycle vs calculated target (200mm/s)
- [ ] Solenoid spring: final spring weight selected, measured retraction time

### Performance data (minimum 10 runs, all logged)

- [ ] Run log table: run number, date, belt speed, time, per-bin totals, accuracy, notes
- [ ] Longest consecutive correct run count
- [ ] Any failures: what failed, what run number, was it repeatable
- [ ] Back-to-back demo simulation (3+ runs in sequence, thermal state logged)

### Failure mode analysis

- [ ] Table: failure type, probability, how detected, system response
- [ ] Undetected failure type: sensor misclassification (routed to wrong bin but physically arrived)
  - Explain why this is acceptable and how it is mitigated (averaging, threshold calibration)

### Feedback loop documentation

- [ ] Diagram: where sensors are, what they detect, what the controller does with each signal
- [ ] Distinguish between real-time feedback (bin confirmation halts on miss) and end-of-run verification (count check)
- [ ] PI controller: block diagram showing input (speed setpoint), measurement, error, output (PWM)
- [ ] Thermal model: explain as a feedback loop (heat accumulates, system responds, loop closes on temperature)

---

## What data the serial output provides automatically

If serial logging is implemented correctly during calibration, the following are generated without manual recording:
- Per-brick log -> accuracy calculation
- Timestamps -> run time, transit times, measured belt speed
- Thermal state -> thermal model validation
- Bin confirmation results -> failure mode analysis data

Do not manually record any of this. Pipe serial to CSV and analyze from the file.

---

## Operator instructions (required deliverable)

docs/competition/OPERATOR_INSTRUCTIONS.md is a placeholder that must become a real document before conference day. It is what the evaluator reads. Write it late in the build process (after the system is finalized and reliable), test it by handing it to someone unfamiliar with the system, and revise until they can run it correctly on the first attempt.

## Timeline for notebook completion

| Section | Data available | Target completion |
|---|---|---|
| Design decisions | Now (documented in architecture files) | April 22 |
| Equations | Now (in architecture files) | April 22 |
| Calibration records | After April 14 integration | April 20 |
| Performance charts | After April 20 reliability runs | April 24 |
| Run log table | After April 20 reliability runs | April 24 |
| Failure mode analysis | After calibration | April 25 |
| Feedback loop documentation | After integration | April 25 |
| Charts | After all data collected | April 26 |

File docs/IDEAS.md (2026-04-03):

# Ideas and Design Exploration

Scratchpad for concepts that are exploratory, not yet architecture. Some of these informed current design decisions. Some may still be relevant if a subsystem needs to be reconsidered.

---

## Belt mechanism selection

There are exactly two coherent belt strategies for this application:

1. **Toothed belt on toothed pulleys** - positive drive, speed mathematically deterministic.
   Requires printed GT2 pulleys with accurate 0.75mm tooth profiles, belt splice with tooth
   alignment. Fabrication risk is non-zero but manageable (droftarts generator is proven).

2. **Flat belt on smooth rollers** - friction drive, needs speed feedback. Best transport
   surface, simplest fabrication (smooth cylinders, flat splice). Hall sensor + PI loop
   closes the speed determinism gap at the cost of ~30 lines of firmware.

"Toothed belt on smooth rollers" is not a coherent strategy: GT2 teeth on a smooth PLA
roller contact only at tooth tips (discrete, deformable neoprene pads with air gaps).
The Euler belt equation requires continuous surface contact. Effective mu is lower than
a flat belt on the same roller. This approach has the downside of friction drive (slip)
without the upside of positive drive (teeth engaging pulleys). Rejected.

**Current design: Strategy 2 (flat neoprene belt, Hall PID)**
Neoprene rubber strip (~25mm wide) on smooth printed rollers. Motor D-shaft rigid coupling
to drive roller (zero slip at that joint). A3144 Hall sensor + 2 magnets on idler roller
feed a PI loop that corrects speed drift from voltage sag and micro-slip. Transport surface
is smooth neoprene - better grip on ABS bricks than GT2 backing.

**Fallback if friction test fails (day-1):**
Add heat-shrink sleeve to drive roller, then rough with 120-grit. If still failing: GT2
hybrid (6mm GT2 belt connects motor to roller shaft with positive drive, neoprene belt
wraps rollers for transport). This bounds all slip to the roller-belt interface.

Rejected immediately: gravity rollers (LEGO bottom geometry catches), linear pusher
(serial: 70+ sec for 24 bricks), O-ring cord (line contact, co-planarity problems).

---

## Alternative diverter mechanisms (considered during design)

Every design was evaluated against the core constraint: sort at 200mm/s belt, 179ms timing window.

**Direct solenoid pusher: current design**
Solenoid rod pushes a face plate directly into the brick. Spring return passive. 40ms on-time.
No lever arm, no pivot. Simpler and more reliable than lever designs. Chosen.

**Solenoid plow with lever arm (considered, rejected)**
Lever amplifies short solenoid stroke to longer plow tip travel. More parts, more failure modes.
Direct pusher achieves adequate travel without a lever. Rejected in favor of direct push.

**Servo flap**
Weakness: 100-150ms sweep and return time. Eats the entire inter-brick window. Throughput drops to 2-3 bricks/second. Not viable at target speed.

**Solenoid puller / fast retractor**
Spring does the divert, solenoid holds retracted (neutral) and releases to snap. Spring snap is faster than solenoid pull. Rejected: solenoid is energized most of the time, inverting the heat profile. Current design has solenoids off by default (thermally better for the 33% default-path bricks).

**Paddle wheel / continuous rotation**
Weakness: timing is mechanically coupled to belt speed, requires synchronization. One paddle per bin path, significant footprint. No selective control without a clutch. See ARCHITECTURE.md for full analysis.

**Pop-up gate (pin through belt)**
Weakness: GT2 belt cannot be slotted without structural failure. Requires a second mechanism to clear the brick. Physically stops bricks rather than deflecting them, which means bounce and jam risk.

**Track diverter (physical rail switches)**
Weakness: inertia cost on both brick and mechanism. Like a pop-up gate but larger footprint. Mechanically interesting but slower than solenoid plow.

**Conveyor -> solenoid queued tilting platform**
A short platform between belt segments that tilts to route the brick to one side. Weakness: cost of inertia (needs a lip to slow brick down before tilt), gravity-friction speed limits return, more moving mass than a plow arm. Complex to mount at belt speed.

**Diagonal conveyors that reverse to collect**
Multiple angled belts that redirect by reversing. Weakness: inertia at belt transitions, significant footprint and complexity. Worth revisiting only if current design hits a throughput wall.

**Omnidirectional ball / pop-up perpendicular conveyor**
An omnidirectional wheel or roller array that activates to push bricks sideways off the main belt. Weakness: inertia, requires brick to be nearly stationary or moving slowly relative to the crossbelt. Not viable at 200mm/s on a 2ft platform.

---

## Puller vs pusher solenoid timing optimization

For any solenoid-actuated mechanism, consider which direction is solenoid-driven vs spring-loaded. The puller variant: spring loads the active position, solenoid holds the neutral position. Active movement is instant (spring snap); retraction is solenoid-speed.

For the direct pusher: the solenoid fires the push (fast, ~10ms), spring returns the rod to rest (passive). The push is on the critical path (must reach the brick in the right window). The return is not critical (brick has already been deflected). This is already optimized: fast direction = solenoid, return direction = spring.

If a future design needs faster return and slower extension, invert the geometry.

---

## Wall power vs battery

For calibration sessions, a bench supply is more stable than LiPo. However it must never be used for logged runs or demo.

If the competition venue allows a wall outlet, a 5V 3A regulated wall adapter would be more stable than LiPo for demo. TSA competitions typically do not guarantee outlet access at the judging table. Assume battery only for competition.

The bulk capacitor on the logic rail (1000uF, see ELECTRICAL.md) partially addresses supply stability by buffering transients regardless of power source.

---

## Possible additions if time permits

These are lower priority and should only be attempted after the core system is reliable and all 10 reliability runs are logged.

- **PI speed controller** (fully detailed in EMBEDDED.md): closed-loop belt speed using slotted disk encoder
- **Web server logging** (in EMBEDDED.md): live JSON event feed over WiFi during calibration
- **Slow demo mode**: second button halves belt speed and slows animations. Useful during judge explanations
- **Brick counter on display**: large text showing bricks sorted out of 24, visible from across the table
- **Break-beam at chute exit**: confirms escapement fired and brick left the chute before entering the sensing zone, one more feedback point

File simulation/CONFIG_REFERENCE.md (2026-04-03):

# Simulator Config Reference

Open `simulator.html` in any browser. No server, no install, no build.

All defaults in the simulator match `firmware/src/config.h` exactly.
When you change a value in config.h, update the matching `DEFAULTS` object
in simulator.html and they stay in sync.

---

## How the simulation works

The simulator is a discrete event model, not physics. It assumes:
- The belt moves at exactly `BELT_TARGET_MM_S` (no slip, no wobble)
- Every brick is classified correctly (sensor noise is a calibration problem, not a design problem)
- Solenoids fire and retract on schedule

What it does model accurately:
- Timing: release intervals, sensing windows, solenoid phases, bin transit times
- Throughput math: escapement rate vs belt capacity
- Color sample count at any speed/integration combination
- Thermal heat accumulation and exponential decay across back-to-back runs
- Warnings when parameter combinations would cause real hardware problems

Use the simulator to understand tradeoffs. Use the serial log during calibration
to measure what actually happens.

---

## Parameters

### Escapement

**Release speed** - `STEPPER_SPS_NORMAL` - default 800 sps

Steps per second the stepper motor runs to release one brick. One full rotation
(200 steps) releases one brick. So:

```
bricks/sec = sps / steps_per_rev = 800 / 200 = 4 bricks/sec
release interval = 1000 / 4 = 250ms between bricks
run time (24 bricks) ≈ 24 / 4 = 6s + transit time ≈ 8-9s total
```

Tuning strategy: start at 800. Run 3 full sets. If accuracy holds at 95%+, go
to 1000. Increment by 200 until accuracy degrades or step-skipping is audible.
Document each level. The TMC2209 handles 2000+ sps. The practical ceiling is
color sensor sample count (8 samples minimum) and NEMA 11 torque under load.

When thermal WARNING or DANGER kicks in, the firmware automatically drops to
533 sps or 267 sps respectively. The simulator shows this in the thermal section.

**Steps per revolution** - `STEPPER_STEPS_PER_REV` - 200 (locked)

Full-step NEMA 11, 1.8 degrees per step. Not tunable. Shown for reference.

---

### Belt

**Belt speed** - `BELT_TARGET_MM_S` - default 200 mm/s

How fast the belt surface moves. The belt must move faster than bricks arrive
or they pile up at the escapement:

```
belt capacity (bricks/sec) = belt_speed / brick_spacing_mm
                            = 200 / 28 = 7.14 bricks/sec

margin = (7.14 - 4.0) / 4.0 = +78% headroom at defaults
```

78% headroom is comfortable. The simulator warns if this goes negative.

Belt speed also drives color sample count and size detection timing. Faster belt
means fewer samples and tighter size margins. The simulator shows both.

The JGB37-520 at 6V is rated 600 RPM no-load. Under real motor load and with
belt friction it will run slower. The motor load factor (65% default) estimates
this. Actual speed is measured empirically during calibration.

**Motor load factor** - derived - default 65%

Estimate of how much the motor slows under real belt and brick load vs no-load
spec. 65% is a reasonable starting point for a gearmotor with belt tension.
Measure actual speed during calibration and update this value.

```
estimated loaded RPM = 600 RPM * 0.65 = 390 RPM
belt speed = (390 / 60) * (pulley circumference)
pulley: GT2, 20 teeth, 2mm pitch -> circumference = 40mm
belt speed = 6.5 * 40 = 260mm/s at load (65% of no-load)
```

The actual belt speed is set by the PWM duty cycle on the L298N. The PI
controller (when implemented) closes the loop using the encoder. This parameter
is informational for the simulator's capacity calculation.

**Motor no-load RPM** - derived - default 600 RPM

JGB37-520 at 6V is rated 600 RPM no-load. Used with the load factor above.

---

### Sensing Zone

**Beam spacing** - `BEAM_GAP_MM` - default 19 mm

Physical distance between the two IR break-beam pairs in the sensing zone.
This is fixed in CAD. Changing it in the simulator shows what would happen
with a different mechanical layout.

The geometry:
```
2x2 brick: 15.8mm long < 19mm gap -> never breaks beam 2 -> classified 2x2
2x3 brick: 23.7mm long > 19mm gap -> breaks beam 2 -> classified 2x3

2x3 signal window = 19mm / 200mm/s = 95ms (time from beam1 break to beam2 break)
```

The 7.9mm length difference between bricks is the entire classification signal.
19mm gap is the key that makes it work: larger than 2x2 (15.8mm), smaller than 2x3 (23.7mm).
Any gap between 15.8mm and 23.7mm works. 19mm is the midpoint.

**Size timeout** - `SIZE_TIMEOUT_MS` - default 150 ms

If beam 2 does not break within this window, the brick is classified 2x2.
Must be above the 2x3 signal window (95ms at 200mm/s) with enough margin
to handle belt speed variation:

```
at 200mm/s: 2x3 signal = 95ms. timeout = 150ms. margin = 55ms. Good.
at 240mm/s: 2x3 signal = 79ms. timeout = 150ms. margin = 71ms. Better.
at 150mm/s: 2x3 signal = 127ms. timeout = 150ms. margin = 23ms. Tighter.
```

The simulator warns if margin falls below 20ms.

**Color integration time** - `COLOR_INTEGRATION_MS` - default 2 ms

How long the TCS34725 takes per reading. The hardware minimum is ~2.4ms.
The firmware uses 2ms as a target; actual integration is rounded up by the driver.

Samples per brick at defaults:
```
dwell time = brick_length / belt_speed = 15.8mm / 200mm/s = 79ms
samples = floor(79ms / 2ms) = 39 samples
```

39 samples gives very high confidence in the averaged R/(R+G+B) ratio.
The minimum for reliable classification is 8 samples. The simulator
shows sample count in the sensing metrics and warns below 8.

---

### Solenoid Timing

Three solenoids, one per plow. Each fires independently. The most frequent
brick type (2x3 blue, 8/24) takes the default path with no solenoid fire.
Total fires per run: 16 (6 + 6 + 4).

**Full power duration** - `SOL_FULL_MS` - default 20 ms

How long the solenoid gets 100% PWM to reach full stroke extension.
Too short: plow does not fully extend and brick deflection is incomplete.
Too long: unnecessary heat with no benefit once stroke is complete.
20ms is conservative for a 0530 push-pull solenoid with ~10mm stroke.

**Hold duty cycle** - `SOL_HOLD_PWM` (40%) - default 40%

After full extension, PWM drops to 40% to hold position against the spring.
40% maintains extension while reducing heat by ~60% versus continuous full power.
Lower hold = less heat, but if too low the spring overcomes the hold and the
plow retracts mid-brick. 40% is the starting point; confirm against your spring
selection during calibration.

`SOL_HOLD_PWM = 102` in config.h (102/255 = 40%).

**De-energize time** - `SOL_DEENERGIZE_MS` - default 280 ms

Total time solenoid stays energized (full power phase + hold phase) before
turning off and letting the spring return the plow.

The brick must fully clear the plow before de-energize:
```
brick arrives at plow: T_classified + sol_lead_ms = T_classified + 150ms
2x3 brick clears plow: +23.7mm / 200mm/s = +118.5ms after arrival
total from T_classified: 150 + 118.5 = 268.5ms

de-energize at 280ms -> 11.5ms margin after brick clears. Fine.
```

The simulator warns if de-energize happens before the brick clears.

After de-energize: spring return takes ~20ms. Plow is reset and ready.

**Sensor-to-plow travel** - `SOL_LEAD_MS` - default 150 ms

How long it takes a brick to travel from the sensing zone to plow 1.
The solenoid fires the instant classification completes. The brick is still
traveling toward the plow. This is the pre-set window.

```
150ms lead at 200mm/s = 30mm from sensor to plow 1
solenoid actuation: ~10ms
pre-set margin: 150 - 10 = 140ms before brick arrives
```

140ms is enormous margin. The solenoid is fully extended and settled
long before the brick arrives. Update from actual CAD measurements
of sensor-to-plow-1 distance once the frame is assembled.

Plows 2 and 3 are further along the belt, so their pre-set margins are
even larger. The `SOL_LEAD_MS` value only needs to cover plow 1 (closest to sensor).

---

### Thermal Model

The thermal model protects hardware during back-to-back runs. It is not
a real temperature model - it is a dimensionless heat accumulator that
triggers escalating slowdowns when actuators are stressed.

Each actuator (3 solenoids + stepper) tracks heat independently.
Heat accumulates on every fire and decays exponentially when idle.

```
on fire:         heat += heat_per_fire (clamped at 1.0)
each second idle: heat = heat * (1 - cooling_pct/100)
```

With `cooling_pct = 50`, heat halves every second. A solenoid firing
at 4 bricks/sec (4 fires per 6 seconds, interleaved) reaches roughly:

```
steady-state heat ≈ heat_per_fire / (1 - (1 - cooling_pct/100)^interval_sec)
with cooling_pct=50 and interval ~1sec between same-plow fires:
≈ 0.15 / (1 - 0.5) = 0.30
```

0.30 is well below WARNING (0.60). A single run at defaults never
triggers thermal throttling.

Thermal throttling becomes visible during back-to-back runs. Run the
simulator with `num_runs = 3` and `sequence = worst_case` to see it.

**Heat per solenoid fire** - `THERMAL_HEAT_PER_SOL` - default 0.15

**Heat per stepper release** - `THERMAL_HEAT_PER_STEP` - default 0.05

**Cooling percent** - `thermal_cooling_pct` (simulator only) - default 50%

0% = no cooling at all (heat only accumulates). 50% = heat halves every
second. 100% = instant reset to zero every second. This replaced the old
`THERMAL_DECAY_RATE` parameter which had confusing behavior above 1.0.
The underlying decay rate passed to `decayHeat()` is `(100 - pct) / 100`.

Note: `thermal_cooling_pct` is a simulator-only tuning parameter. The
firmware uses `THERMAL_DECAY_RATE` in config.h. Map between them:
`THERMAL_DECAY_RATE = (100 - thermal_cooling_pct) / 100`.

**Warning threshold** - `THERMAL_WARN_LEVEL` - default 0.60

Above this: escapement slows to `STEPPER_SPS_WARNING` (533 sps, 2.7 bricks/sec).

**Danger threshold** - `THERMAL_DANGER_LEVEL` - default 0.85

Above this: escapement slows to `STEPPER_SPS_DANGER` (267 sps, 1.3 bricks/sec).

---

### Bin distances (geometry - update from CAD)

```
bin_distances_mm: [250, 280, 310, 360]
```

Distance from the sensing zone center to each bin entrance, in mm.
These are estimates. Actual values depend on frame layout. Update them
after dry assembly by measuring the physical sensor-to-bin-entrance path.

Bin assignment:
```
bin 1 (2x2 BLUE): 250mm from sensor, plow 1
bin 2 (2x2 RED):  280mm from sensor, plow 2
bin 3 (2x3 RED):  310mm from sensor, plow 3
bin 4 (2x3 BLUE): 360mm from sensor, default (no plow)
```

The bin confirmation timeout (`CONFIRM_TIMEOUT_MS = 500ms`) must be
larger than the longest transit time:

```
longest transit: 360mm / 200mm/s = 1800ms -> well within 500ms? No.
```

Wait - the bin distance is measured from the sensor. At 200mm/s:
`360mm / 200mm/s = 1800ms`. The `CONFIRM_TIMEOUT_MS = 500ms` is
measured from when the routing command fires, not from when the brick
enters the sensor. The brick is already traveling when routing fires.
Actual timeout is from T_classified (which is ~150ms after T_sense).
Remaining travel = (bin_dist - sol_lead_dist) / speed = (360 - 30) / 200 = 1.65s.
500ms is too short for bin 4. This is an open calibration item - verify
sensor-to-bin distances in dry assembly and recalculate confirm timeout.

This is tracked in docs/ISSUES.md.

---

### Brick counts and routing

```
2x3 BLUE: 8 bricks -> plow 0 (no fire, default path) -> bin 4
2x2 BLUE: 6 bricks -> plow 1 -> bin 1
2x2 RED:  6 bricks -> plow 2 -> bin 2
2x3 RED:  4 bricks -> plow 3 -> bin 3
```

Default path carries the most common type. 16 total solenoid fires per run.
Per solenoid: 6, 6, 4. Heat distribution is uneven but within thermal budget.

Expected end-of-run bin counts: **6, 6, 4, 8**.

---

### Sequence options

Controls the order bricks are released per run. The 24 bricks are always the
same set (6 + 6 + 4 + 8); only their order changes.

**random** - Fisher-Yates shuffle of the 24-brick set each run. Use with
`num_runs = 100` to sample outliers. brickLog will have 2400 entries; the
worst-case routing error count across 100 shuffles shows up in warnings.

**default_order** - 2x2 BLUE, 2x2 RED, 2x3 RED, 2x3 BLUE in blocks. Same
as what you would get loading bins by type. Mostly tests nominal operation.

**worst_case** (default) - Groups all same-type bricks consecutively:
all 8 x 2x3 BLUE, then 6 x 2x2 BLUE, then 6 x 2x2 RED, then 4 x 2x3 RED.
The active solenoid fires repeatedly with no cooling time between same-type
runs. Maximizes heat accumulation. Use to find the thermal ceiling at a given
sps before throttling kicks in.

**worst_case_accuracy** - Alternates plow-diverting bricks with default-path
bricks: [plow1, default, plow2, default, plow3, default, ...]. The plow fires,
then the very next brick is a default-path brick arriving before the plow has
fully retracted. At high sps (> ~714) the default brick arrives while the plow
is still extended and gets caught by it - a routing error. Use this sequence
to find the maximum sps where cross-plow conflicts appear.

The two worst-case sequences stress different failure modes:
- `worst_case` -> thermal throttling, solenoid heat
- `worst_case_accuracy` -> routing conflicts, retract timing margin

---

## Warnings explained

**Belt is bottleneck** - error
Belt capacity (belt_speed / brick_spacing) is less than escapement rate
(sps / steps_per_rev). Bricks arrive faster than the belt can carry them
away. Jam at the escapement. Fix: increase belt speed or reduce sps.

**Insufficient color samples** - warning below 8, error below 4
Fewer than 8 samples puts the averaged ratio at risk from single-reading
noise. The TCS34725 at 2ms integration gives 39 samples at default speed.
Samples drop if belt is fast or integration time is long.

**Size timeout too close to 2x3 signal** - warning
The 2x3 brick produces a signal at `beam_gap / belt_speed` ms. The timeout
must be above this with at least 20ms margin for belt speed variation.
If timeout < signal window: 2x3 bricks are misclassified as 2x2.

**Solenoid de-energize too short** - error
The solenoid turns off before the brick has fully passed the plow. The spring
yanks the plow back under the brick and jams it. Fix: increase de-energize
time or reduce sol_lead_ms (move plow closer to sensor).

**Plow overlap** - warning
Same plow needs to fire again before it has finished de-energizing from the
last fire. This happens when same-type bricks are consecutive and sps is high.
Different plows can fire simultaneously without any issue. Only the same plow
firing twice within sol_deenergize_ms matters. The simulator checks this
against the actual sequence order.

**Thermal danger reached** - info
Appears in warnings tab after a simulation where heat exceeded the danger
threshold. Not necessarily a problem - the system throttles and recovers.
If it happens in a single run at competition speed, consider adjusting
thermal parameters or increasing decay rate.

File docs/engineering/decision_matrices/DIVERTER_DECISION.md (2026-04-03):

# Diverter Mechanism Decision - Unbiased Design Review

## Decision criteria

This document records the evaluation of 7 diverter options for the brick sorter.
Evaluated against scoring criteria (first place, not participation). Options were
ranked on reliability, timing tolerance, fabrication risk, and scoring visibility.
No options eliminated for being "too hard" - only eliminated if genuinely infeasible
or if they score worse on all relevant criteria.

Decision: direct solenoid pusher. See ranking section at end of document.

---

## What this system does

Sorts 24 LEGO bricks by size (2x2 vs 2x3) and color (red vs blue) into 4 bins,
automatically, on a conveyor, in a single run. Operated by a judge who has never
seen the system, following written instructions only. No team present.

Brick dimensions:
- 2x2: 15.8mm x 15.8mm x 11.4mm, square footprint
- 2x3: 23.7mm x 15.8mm x 11.4mm, longer
- All bricks weigh approximately 2-4 grams

Brick distribution per run:
- 2x3 blue: 8 (33%)
- 2x2 blue: 6 (25%)
- 2x2 red: 6 (25%)
- 2x3 red: 4 (17%)

---

## Scoring rubric (100 points total)

- Inventor's Log: 20 points (documentation, engineering notebook)
- Solution to Problem: 60 points (does it work, reliability, accuracy,
  engineering quality, decision documentation with rejected alternatives)
- Programming Structure: 20 points (code organization, readability)

Speed is NOT explicitly in the rubric. We assume that a faster sorter will stand out, making them think it is a better engineered design, but it is only an assumption

A 12-second reliable sort may score identically to an 8-second reliable sort, or the 8 second could score better. If they think the speed was good engineering, I believe they will reward it. Thats why I want to run the belt fast and escapement fast.

---

## Hard constraints

- Footprint: 610mm x 610mm maximum, cannot exceed this
- Power: LiPo battery
- Microcontroller: ESP32
- Competition date: May 1 2026
- Parts order deadline: tonight (March 21 2026)
- Parts arrival: approximately April 1 2026
- Build and calibration window: April 1 to April 27 (approximately 4 weeks)
- Team size: 2 people
  - Person A: embedded firmware focus, can write firmware for any mechanism
    in approximately 30-60 minutes once design is decided
  - Person B: CAD/mechanical focus, availability this week is uncertain,
    which is part of why this decision is open
- Budget: approximately $130-150 total

---

## Parts already in cart (these are sunk costs, ignore them as a constraint)

The following are already in the cart but should NOT bias the decision.
If the right answer requires different parts, order them or remove parts. All parts are aliexpress except high accuracy like LiPo, the break beams used to measure brick size, etc. These are listed only
so you know what is available without additional shopping:

- JF-0530B solenoids 5V x4 (~$1.10 each)
- Torsion spring assortment
- NEMA 11 stepper + TMC2209 (escapement)
- JGB37-520 6V 600RPM gearmotor (belt drive)
- L298N motor driver
- TCS34725 color sensor
- IR break-beams x6 pairs
- LM2596 buck converters x2
- GT2 timing belt + pulleys (could get more depending on the method, not ordered yet)
- Wide flat rubber belt (for brick transport surface, we havent added this to cart yet, how wide? it depends on the method, we could also get multiple depending on the method)
- ESP32, caps, wire, perfboard
- Wires, solder, perf board, other misc

Parts NOT in cart that could be added tonight at low cost:
- MG996R servo: ~$3-4 each (metal gear, 0.17s per 60 degrees at 6V)
- Additional small DC gearmotors: ~$3-6 each
- Additional belt/roller materials: ~$3-5
- Additional L298N or MX1508 drivers: ~$1-2 each
- Adafruit break beams for accurate size measurement
- LiPo(s)
- LiPo charger
- Anything else you want

---

## Sensing and classification (decided, not open, included for context)

Size classification: two IR break-beams 19mm apart along the belt axis.
Hardware timer measures gap between beam 1 and beam 2 breaking.
- 2x3 brick (23.7mm): longer than 19mm gap, breaks both beams, gap ~95ms at 200mm/s
- 2x2 brick (15.8mm): shorter than 19mm gap, beam 2 never breaks (timeout)
This is binary, hardware-timed, essentially immune to noise.

Color classification: TCS34725 RGB sensor facing down through a shroud.
Samples continuously from beam 1 break, ~32 samples per brick at 200mm/s.
Averages all valid samples, classifies by R/(R+G+B) ratio.
Red LEGO has strong red spectral signature, blue LEGO has strong blue signature.
Separation is large and reliable.

Both sensors output classification result approximately 150ms after brick enters
the sensing zone. This is the time available for the diverter to pre-set before
the brick arrives.

---

## Belt and transport (decided, not open, included for context)

Single straight belt. Wide flat rubber surface (~60-80mm wide) on 3D printed
rollers. Belt moves at approximately 200mm/s. Bricks ride on the belt surface
and travel from chute end to bin end in approximately 1.5 seconds.

The belt is the ONLY transport mechanism. All bricks travel the full belt length.
Diversion happens along the belt or at the end of the belt.

---

## The open question: how do we get bricks into 4 different bins?

Below are ALL proposed options. Evaluate each one.

---

### Option A: Solenoid plow with lever arm

Three solenoid-actuated lever arms at three positions along the belt.
Each lever arm has a pivot, a solenoid input arm (8mm), and a plow output arm
(24mm), giving 3:1 mechanical advantage.
Solenoid stroke 10mm becomes 30mm tip travel at the plow face.
30mm tip travel pushes a brick fully across the 25mm belt and into a side bin.
Spring returns the arm to neutral after each actuation.
Fourth bin (most common brick type, 33%) takes the default path with no actuation.

Actuation: solenoid energizes, lever sweeps plow into path in ~10ms.
Return: spring, ~20-30ms.
Total cycle time per actuation: ~50ms.

Three plows at different positions means three decisions happen in parallel as
bricks travel down the belt. Brick 3 can be at plow 1 while brick 4 is being
classified. The decisions are off the critical path.

At 4 bricks/sec (250ms between releases): 200ms margin after 50ms actuation.
At 6 bricks/sec (167ms between releases): 117ms margin.
At 8 bricks/sec (125ms between releases): 75ms margin.

Open questions / risks:
- Pivot hinge design undecided. Options: M2 bolt through printed bracket with
  brass tube bushing, or small ball bearing pressed into the arm.
- CAD person concern: lever arm might be flimsy, pivot might dislodge.
- Channel wall needs a slot for the lever sweep arc.
- Force margin against brick is approximately 94x (solenoid force >> required).

---

### Option B: Servo plow (direct sweep, no lever)

Same layout as Option A but with MG996R servos instead of solenoids and levers.
Servo horn directly pushes a plow arm into the brick path.
No lever, no spring, no pivot. Servo holds position, returns on command.

MG996R: 0.17s per 60 degrees at 6V. For 90-degree sweep: ~0.25s.
Return sweep: ~0.25s. Total cycle time: ~500ms.

At 4 bricks/sec (250ms between releases): cycle time EXCEEDS inter-brick window.
The servo cannot complete extension and return before the next brick arrives at
the same plow position.

This means the escapement must be slowed to keep inter-brick windows above 500ms:
500ms window = 2 bricks/sec = 24 bricks in ~12+ seconds.

Three servos in parallel still helps (different plows handle different bricks)
but the worst-case plow (2x2 blue, 6 bricks at 25% frequency) sees a brick
every 4th release. At 4 bricks/sec that is one 2x2-blue brick every second,
which is within the servo's recovery time. The constraint is only binding if
the same plow must fire twice within its cycle time.

At 4 bricks/sec with the interleaved brick sequence, no single plow fires more
than once per ~750ms. So servos MAY be viable at 4 bricks/sec if the firmware
sequences releases to avoid back-to-back same-plow firings.

At higher speeds (6+ bricks/sec), same-plow collision becomes likely.

Parts: MG996R x4, not currently in cart, ~$12-16 to add.
CAD: simpler than option A (no pivot, no lever ratio calculation).
Firmware: trivial, PWM position control.

---

### Option C: Wide-face direct solenoid push (no lever)

Solenoid pushes directly sideways with a wide flat face plate (~20-25mm wide)
attached directly to the solenoid rod. No lever amplification.

JF-0530B stroke: approximately 10mm.
Belt width: ~60-80mm.
Bin entrance must be positioned so a 10mm push delivers brick fully into it.
This constrains channel geometry: bin opening must be within 10mm of brick edge.

Face plate width 20-25mm catches slightly yawed bricks.
Actuation and return timing: identical to option A (solenoid + spring).
Tip travel is 10mm instead of 30mm.

CAD: simplest of all solenoid options. No pivot, no lever.
The constraint is channel geometry: bins must be adjacent to belt, not offset.
If channel geometry can accommodate this, it eliminates the pivot concern entirely.

Risk: 10mm stroke may be insufficient if the belt is wide. Depends on exact
channel layout. Needs to be verified in CAD before committing.

---

### Option D: Rotary bin selector (disk at belt exit)

A single 4-chamber rotating disk positioned at the belt exit point.
Bricks fall off the end of the belt and into whichever chamber the disk has
rotated to present. One motor drives the disk.
Belt has no diverters at all. Clean straight run.

Timing: brick exits belt approximately 1.5 seconds after release.
Classification result is available at ~150ms after brick enters sensing zone.
Time available for disk rotation: ~1.35 seconds. This is generous.

But the system is serial: cannot release the next brick until the disk has
rotated, settled, and confirmed position. Otherwise two bricks arrive at the
exit while the disk is mid-rotation.

With a servo driving the disk: 270-degree worst-case rotation at 0.17s/60deg
= ~0.75s + settling ~0.25s = ~1s between bricks minimum.
24 bricks at 1 brick/sec = 24 seconds minimum, plus overhead.

With a stepper driving the disk: faster rotation possible but requires
acceleration ramping firmware to stop accurately at 4 positions under varying
load (brick weight shifts as chambers fill). Position encoder needed.

Bin confirmation: one IR sensor per chamber opening.
CAD: 4-chamber disk, motor mount, position sensing.
Parts: one additional motor + driver, not currently in cart.

---

### Option E: Glued blocks on main conveyor belt as brick separators, with lateral solenoid pushers

Physical dividers glued onto the wide flat belt surface create individual cells,
one brick per cell. This eliminates timing-based brick spacing: the belt geometry
handles it mechanically.

With bricks pre-separated into cells, a lateral pusher (solenoid or servo) fires
when each cell aligns with the correct bin opening. The pusher does not need to
work against a moving brick - the brick is already in a defined location.
Timing becomes positional rather than velocity-based.

Pusher timing: fire when encoder confirms the correct cell is at the bin opening.
This is deterministic and does not depend on belt speed accuracy.

Belt construction concern: divider blocks are glued onto a rubber belt that
flexes around the rollers at each end. The glue joint is stressed in peel on
every rotation. Even low loads cause peel failure over repeated cycles at the
roller radius. This is a material failure mode, not a load failure mode.

Alternative attachment: if dividers are NOT glued but instead are part of a
printed or modular belt surface (e.g., laser-cut flexible sheet with integrated
walls, or 3D printed articulated belt sections), the peel problem disappears.
Custom belt construction is a significant fabrication challenge.

Risk assessment: if belt divider fabrication is reliable, this is a very clean
design. The positional triggering eliminates the tight timing window problem
entirely. The question is entirely about whether the dividers can be attached
durably.

---

### Option F: Zig-zag multi-belt layout

Instead of one straight belt with diverters, multiple shorter belt segments
arranged in a zig-zag or branching pattern. Each branch decision point uses
a simple 2-way diverter, which is easier to execute reliably than a 4-way.

Example layout:
- Main belt feeds a 2-way diverter (left or right)
- Left branch leads to a 2-way diverter (bin 1 or bin 2)
- Right branch leads to a 2-way diverter (bin 3 or bin 4)
Total diverters: 3, all 2-way only.

A 2-way servo diverter is much more viable than a 4-way: only 90-degree sweep
needed, and the inter-brick timing concern is reduced because each diverter only
handles a fraction of total bricks.

The first diverter handles all 24 bricks (must be fast).
Each second-tier diverter handles 12 bricks (half the frequency, more time).

Footprint concern: zig-zag layout must fit within 610x610mm. With a 400mm main
belt and two side branches, this may be tight. Needs a top-down layout sketch
before committing.

CAD complexity: significantly higher than single-belt options. Multiple belt
frames, multiple motors, multiple speed controllers, alignment between segments.
Bricks must transfer cleanly from one belt segment to the next without tumbling.
Transition points between belt segments are a new failure mode.

Parts: 2-3 additional small gearmotors, additional motor drivers, additional
belts and rollers. Approximately $20-30 additional cost.

---

### Option G: Parallel dual-belt with first-stage 2-way diverter

Two belts running side by side. A single 2-way diverter at the chute exit
routes each brick onto belt A or belt B. Belt A leads to bins 1 and 2 (with
a plow or pusher). Belt B leads to bins 3 and 4 (with a plow or pusher).

The first-stage diverter only makes a 2-way decision (much easier than 4-way).
Each belt's plow only makes a 2-way decision (even easier).

Inter-brick timing at the first diverter: still needs to fire and return before
next brick arrives (same constraint as before, but for a 2-way decision only).
A servo doing a 45-degree sweep: ~0.12s. Return: ~0.12s. Cycle: ~250ms.
This exactly matches the 4 bricks/sec inter-brick window. Marginal.

Footprint: two belts side by side, each ~80mm wide plus frame, total ~200mm
across. Plus the main chute and two sets of bins. Needs layout verification.

Parts: second JGB37 motor, second L298N, second belt+rollers, additional plows.
Approximately $15-25 additional cost.

CAD complexity: moderate to high. Two complete belt frames plus the diverter.

---

## What Opus is being asked to produce

Read all options above fully before forming any opinion.

Then produce the following, in this exact order:

### 1. Full ranking (all options, best to worst for winning first place)
One line per option. Format: "Rank N: [Option name] - [one sentence reason]"
Include any hybrid or modified option you think is better than what is listed.

### 2. Winner
State the winner clearly. Full justification covering:
- Why it scores best against the scoring rubric
- Why each other option scores lower (specific reason per option)
- The single biggest risk with the winner and exactly how to mitigate it

### 3. Decision tree
If the winner turns out to be infeasible after trying, what is the fallback.
If that fallback is also infeasible, what is the fallback after that.
Be specific about what "infeasible" means for each - what specific failure
condition triggers the fallback.

### 4. What to order tonight
Specific parts not in the available parts list that are needed for the winner.
Name, quantity, approximate cost, and why each is needed.

### 5. First 48 hours
Concrete tasks for Person A (firmware) and Person B (CAD/mechanical) in the
first 48 hours after this decision is made. Be specific - not "start the CAD"
but "CAD the lever arm: 24mm output arm, 8mm input arm, 3mm pivot hole, print
in this orientation." That level of specificity.

Hard constraint on your output: you must not be undecided. You must produce a
ranked list and a winner. If options are close, break the tie and explain why, but allow a decision tree to adapt to team constraints.

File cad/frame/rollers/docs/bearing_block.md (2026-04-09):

# Bearing Block

## Purpose

Supports the driven 5mm shaft at two points so the shaft load does not reach the motor bearings. Two blocks are needed per shaft.

## Geometry

| Feature | Value |
|---|---|
| Block size | 14mm (X, shaft axis) x 16mm (Y, lateral) x 22mm (Z, height) |
| Shaft bore | 5.2mm diameter, through full X |
| Bearing pocket | 8.15mm diameter, 2.6mm deep from +X face |
| Pocket chamfer | 0.35mm lead-in |
| M3 mounting holes | 2x through Y, at Z = +/-7mm from shaft center |
| M3 nut trap | 2x hex trap at -Y face, M3 nut (5.5mm AF x 2.6mm deep) |

## Bearing used

MR85ZZ: 5mm ID, 8mm OD, 2.5mm wide.

Two blocks per shaft. Order does not matter as long as the bearing pocket faces outward on both ends.

## Shaft layout with two blocks

Position blocks symmetrically around the drive roller. Example layout for 25mm wide channel with 3mm walls:

| Component | X position (from roller center) |
|---|---|
| Drive roller center | 0 |
| Drive roller edge (flange) | +/- 14.5mm |
| Bearing block center | +/- 21.5mm (adjust to clear roller) |
| Bearing block outer face | +/- 28.5mm |
| Driven pulley (purchased 20T) | beyond outer bearing block on one side |

Adjust spacing based on actual frame wall positions. The shaft (200mm) has ample length.

## Mounting to frame

Mounting holes run through the Y faces (lateral). The block bolts to the frame side wall with 2x M3 screws from outside.

M3 nut traps are at the -Y face (inner face, toward the channel). Insert M3 hex nuts before assembly since the inner face may not be accessible after the block is mounted.

## Print orientation

Best circularity for the bearing pocket: print with shaft axis (X) vertical. The pocket then faces upward and prints without support.

If printing flat (X horizontal), verify bearing press-fit using the bearing coupon before printing full blocks.

## Bearing press fit

The pocket is 8.15mm diameter. For MR85ZZ (8mm OD), this gives 0.15mm clearance. Light press fit is expected. If the pocket is slightly oversized from your printer, a small drop of retaining compound is acceptable as a backup.

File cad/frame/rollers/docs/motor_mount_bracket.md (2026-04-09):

# Motor Mount Bracket

## Purpose

Mounts the NEMA17 to the frame with 8mm of belt tension travel in the Y direction.

## Geometry

| Feature | Value |
|---|---|
| Overall size | 70mm x 70mm x 4mm |
| Motor pilot clearance | 22.4mm diameter (through) |
| Motor M3 holes | 4x, 3.4mm dia, on 31mm square pattern |
| Frame slots | 4x, 3.5mm wide x 12mm long, Y-oriented |
| Frame slot centers | 28mm from bracket center in X, 28mm in Y |
| Tension travel | ~8.5mm (slot length minus slot width) |
| Print orientation | Flat, Z = thickness |

## Slot axis and tension direction

Slots are elongated in Y. The bracket slides in Y relative to the frame to adjust belt tension.

Move the bracket in +Y (away from the driven shaft) to increase center distance and tension the belt.

Frame bolts (M3) pass through the frame wall, through the bracket slots, and are secured with nuts on the other side. Loosen to slide, tighten to lock.

## Motor attachment

Motor face screws (M3) thread directly into the NEMA17 face from the bracket back. The 22.4mm center hole clears the motor pilot boss (22mm OD) and any motor shaft hardware on the far side of the bracket.

Motor pulley (20T GT2, purchased) mounts on the motor shaft on the frame side of the bracket (not between motor and bracket).

## Print and assembly notes

- Print flat with motor-face side down on the bed for best pilot bore surface.
- All holes are vertical, no support required.
- M3 nut traps are not present in this bracket; use standard M3 nuts against the frame face.
- Hub wall material between motor holes and frame slots is approximately 12mm, sufficient for M3 clamping loads.

## Nominal placement (Fusion)

Motor shaft center is 80mm from the driven shaft center in the belt direction (Y axis in conveyor layout). Place this bracket so the bracket center aligns with the motor shaft center at that 80mm offset.

Driven shaft and motor shaft must be parallel (both along X axis) and coplanar in Z unless the frame intentionally places the motor lower for packaging reasons.

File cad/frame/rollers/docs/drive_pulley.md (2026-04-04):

# drive_pulley.scad Part Card

## Role

- Powered roller that drives the conveyor belt strip.
- Mounts on the motor shaft and transmits motor torque to belt motion.

## Mates With

- NEMA 17 conveyor motor shaft
- Belt strip in the 20mm channel
- Idler roller on opposite end of belt path

## Required Hardware

- One M3 socket head screw for the clamp
- One M3 hex nut for the clamp nut trap
- Motor shaft and mounting hardware from conveyor motor assembly

## Core Geometry

- 25mm outer diameter roller body
- 20mm contact face width
- 2mm flanges on both sides
- Split clamp shaft-fit hub

## Locked Truth Dependency

- Belt strip target and channel constraints that support widthwise brick transport.
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

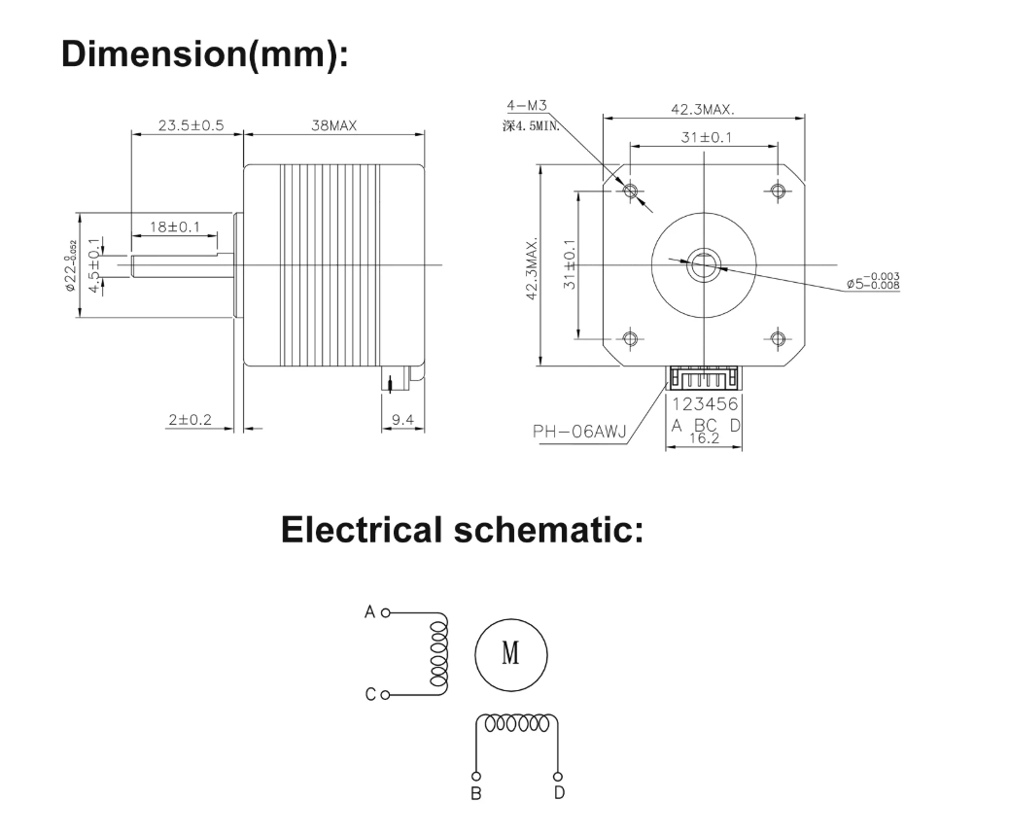
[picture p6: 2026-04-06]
docs/datasheet/motion/nema17/images/schematic.png

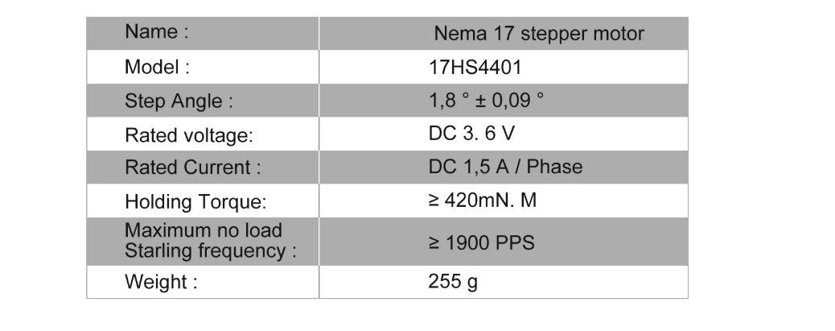
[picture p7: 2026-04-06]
docs/datasheet/motion/nema17/images/specs.png

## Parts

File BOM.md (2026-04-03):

# Bill of Materials

Order today March 18 2026. AliExpress lead time is 10-15 days (expect arrival March 28 - April 2). Adafruit ships in 2-5 days. Do not wait.

---

## AliExpress (order first -- longest lead time)

| Part | Search term | Qty | Est. cost | Notes |
|---|---|-----|---|---|
| JF-0530B solenoid 5V | JF-0530B solenoid | 3 | $6-9 | plow actuation |
| NEMA 11 stepper motor | NEMA 11 stepper 28mm | 1 | $5-8 | escapement drive |
| A4988 stepper driver module | A4988 stepper driver | 2 | $2-3 | 1 primary, 1 spare -- these die easily |
| TT gearmotor 6V | TT motor gearmotor 6V | 2 | $3-4 | 1 belt drive, 1 spare |
| L298N motor driver | L298N module | 1 | $1-2 | belt speed control via PWM |
| LM2596 buck converter | LM2596 step down | 2 | $2-3 | one per power rail |
| GT2 belt 400mm closed loop 6mm | GT2 400mm belt 6mm | 2 | $3-4 | 1 primary, 1 spare |
| GT2 20-tooth pulley 5mm bore | GT2 20 tooth pulley 5mm | 4 | $3-4 | 2 primary, 2 spare |
| M3 hardware kit | M3 bolt nut standoff kit | 1 | $3 | structural fasteners |
| M2 hardware kit | M2 bolt nut kit | 1 | $2 | plow pin connections |
| Torsion spring assortment | torsion spring assortment small | 1 | $3-4 | plow arm return -- test with actual solenoid |
| 100uF 25V electrolytic capacitor | 100uf 25v electrolytic capacitor | 10 | $1 | A4988 motor input cap (critical) + spares |
| 1000uF 25V electrolytic capacitor | 1000uf 25v electrolytic | 5 | $1-2 | bulk cap for logic rail ESP32 supply |
| H206 slot optocoupler | H206 optocoupler slot sensor | 2 | $1-2 | belt speed encoder (1 primary, 1 spare) |
| Small aluminum heatsink kit | aluminum heatsink kit small | 1 | $2-3 | solenoid bodies |
| Thermal adhesive tape | thermal adhesive tape | 1 | $2 | attaching heatsinks |
| 2S LiPo 7.4V 2000mAh | 2S lipo 2000mah 7.4v | 2 | $16-20 | 1 primary, 1 spare -- competition day power failure is unrecoverable |
| 2S LiPo balance charger | 2S balance charger | 1 | $5-6 | must test on LiPo before April 20 |
| Perfboard / protoboard | perfboard prototype board | 2 | $2-3 | final permanent wiring (not breadboard) |
| 22AWG stranded hookup wire assortment | 22awg hookup wire kit | 1 | $3-5 | permanent wiring (breadboard jumpers fall out) |

---

## Adafruit (ships fast, order same day)

| Part | Part # | Qty | Cost |
|---|---|-----|---|
| IR break-beam 3mm pair | #2168 | 4 packs | ~$16 |
| TCS34725 RGB color sensor | #1334 | 1 | ~$7 |

4 packs = 8 pairs. 6 needed (2 size sensing + 4 bin confirmation). 2 spare.

---

## Display -- pick one, order same day

| Option | Size | Cost | Notes |
|---|---|---|---|
| Pimoroni 1.3in ST7789 | 240x240 | $10-12 | best panel quality, best ESP32 support -- recommended |
| Waveshare 1.69in ST7789 | 240x280 | $8-10 | slightly larger |
| Generic AliExpress ST7789 | 240x240 | $4-6 | works, QC varies |

Do not order SSD1306. It is monochrome. The animation requires color.
Order one spare display if budget allows -- a dead panel during calibration costs a week.

---

## Local (same day)

| Part | Where | Cost | Purpose |
|---|---|---|---|
| Isopropyl alcohol | pharmacy | ~$3 | cleaning contacts and prints |
| Foam sheet or felt | dollar store | ~$2 | bin liners (if not using printed ramp bins) |

---

## Already owned (verify before ordering duplicates)

- ESP32 DevKit
- 1N4007 flyback diodes (verify quantity -- need 3 minimum)
- Breadboard and jumper wires (for bringup only, not final build)
- Heat shrink tubing
- PLA filament (school printer)
- DC bench supply (development only, never for logged runs or demo)
- Resistor assortment (verify 4.7k available for I2C pullups if needed)

---

## Notes

**Why 2 LiPo batteries?** Competition day power failure with no spare is unrecoverable. Judges may request multiple consecutive demos. Two batteries = peace of mind.

**Why perfboard and hookup wire?** Breadboard jumpers vibrate out. For the final assembled system, everything solenoid-carrying and sensor-carrying needs to be soldered to perfboard. Do not skip this.

**H206 slot optocoupler** is for the belt speed encoder (slotted disk on belt pulley). See EMBEDDED.md for the PI controller approach. Print slots into the pulley face, mount the sensor next to it, get continuous high-bandwidth speed feedback.

**Spring assortment:** test each spring weight against the actual JF-0530B at operating voltage before committing. Target the heaviest spring the solenoid can still overcome -- faster retraction is the goal. The force margin is large (~94x) so there is substantial room to go heavy.

---

## Total estimated cost

$110-135 (up from earlier estimate due to second LiPo, encoder, and permanent wiring materials)

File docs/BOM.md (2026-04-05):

# Bill of Materials

**Source of truth:** `docs/BOM.xlsx` is the authoritative purchase record.

Integrity rule:
- Ordered sections in this markdown may summarize only rows that exist in `docs/BOM.xlsx`.
- If an item is not in the spreadsheet, this file must treat it as `not yet ordered`, `already owned`, or `unconfirmed`.
- Do not turn inferred or recommended parts into ordered purchases.

Current architecture:
- Conveyor drive is an off-axis `NEMA 17` timing-belt stage with a supported roller shaft
- Selector drive is `NEMA 11` stepper

Current receipt status:
- AliExpress orders recorded in `docs/BOM.xlsx` are received.
- Amazon orders recorded in `docs/BOM.xlsx` are not yet received.
- Measurement is allowed for received AliExpress hardware now.
- Amazon-dependent measurements stay blocked until Amazon delivery.

## Receipt checks

**Solenoid recorded in the purchase log:**
`0530 Linear Solenoid Electromagnet 12V` in `docs/BOM.xlsx`.

Important note:
- Repo design documents previously assumed a `6V` JF-0530B variant.
- The spreadsheet purchase log currently points to a `12V` `0530` listing instead.
- Treat the spreadsheet as hardware truth until the received part is measured and photographed.
- Before wiring, verify actual coil voltage, stroke, body size, and current draw on the received unit.

**Color sensor recorded in the purchase log:**
`TCS3200 GY-31 Color Sensor Module` in `docs/BOM.xlsx`.

Important note:
- Repo design documents previously assumed `TCS34725`.
- The spreadsheet purchase log currently points to `TCS3200 GY-31`.
- Treat the spreadsheet as hardware truth until the received module is verified.
- Final firmware pin map and calibration flow must match the actual received sensor.

**Timing-stage purchases:**
- The actionable buying items left today are the timing-stage parts in the audit below.
- Do not buy extra `MR115ZZ` bearings right now. The spreadsheet already records one `10pcs` pack, and current docs call for `2` idler bearings plus `2` supported-shaft bearings, leaving `6` spare.

## Ordered Items From `docs/BOM.xlsx`

### Amazon Mar 25

Spreadsheet trace: `Amazon Mar 25` tab and `Summary` row for March 25.

| Part | Qty | Trace | Notes |
|---|-----|---|---|
| Throzzik 4700uF 25V Electrolytic Capacitor (10pcs) | 1 | `Amazon Mar 25` | `4700uF 25V 16x25mm` |
| Zeee 3S Lipo Battery 2200mAh 50C XT60 (2 Pack) | 1 | `Amazon Mar 25` | `11.1V 2200mAh 50C Shorty Pack XT60` |
| ISDT 608AC Lipo Balance Charger | 1 | `Amazon Mar 25` | `8A 200W 1-6S LiPo/Life/NiMH AC/DC XT60` |
| Waveshare 2inch Mini LCD Screen | 1 | `Amazon Mar 25` | `240x320 IPS ST7789VW SPI 262K RGB` |
| Hosyond ESP32 Dev Board (3 Pack) | 1 | `Amazon Mar 25` | `USB-C WiFi+BT Dual Core CP2102 Arduino IDE` |

Order total from spreadsheet: `$149.52`

### Amazon Mar 31

Spreadsheet trace: `Amazon Mar 31` tab and `Summary` row for March 31.

| Part | Qty | Trace | Notes |
|---|-----|---|---|
| BDS-HOME Spring Assortment Kit (200pcs) | 1 | `Amazon Mar 31` | `200pcs 20 sizes zinc plated compression and extension springs` |
| MAIYUM 63-37 Solder Wire 0.8mm 50g | 3 | `Amazon Mar 31` | `63-37 tin/lead 0.8mm 50g rosin core` |
| 18 AWG Wire 2-Pack Red/Black 25FT | 1 | `Amazon Mar 31` | `18AWG CCA stranded automotive 25FT per color red/black 2-pack` |
| LM2596 DC-DC Buck Converter (5-Pack) | 1 | `Amazon Mar 31` | `3.0-40V to 1.5-35V step down 5pcs` |

Order total from spreadsheet: `$62.87`

### AliExpress Mar 25

Spreadsheet trace: `AliExpress Mar 25` tab and `Summary` row for March 25.

| Part | Qty | Trace | Notes |
|---|-----|---|---|
| TMC2209 Silent Stepper Motor Driver | 3 | `AliExpress Mar 25 / 8210696713975240` | `TMC2209 replaces TMC2208/A4988` |
| ACP4020 40mm Axial Cooling Fan | 3 | `AliExpress Mar 25 / 8210696713805240` | `40x40x20mm DC12V Double Ball No RGB` |
| NEMA 11 Stepper Motor 1.8deg 34mm | 2 | `AliExpress Mar 25 / 8210696713745240` | `2-phase 4-lead 1.8deg 34mm high torque` |
| Raspberry Pi Heatsink Set (3pcs) | 1 | `AliExpress Mar 25 / 8210696713665240` | `Adhesive pure aluminum 3pcs` |
| 1N4007 Rectifier Diode (10pcs) | 1 | `AliExpress Mar 25 / 8210696713645240` | `1A 1000V DO-41 10pcs` |
| Braided PET Cable Sleeve | 1 | `AliExpress Mar 25 / 8210696713955240` | `Black 2m ID 6mm flame retardant` |
| Braided PET Cable Sleeve | 1 | `AliExpress Mar 25 / 8210696713925240` | `Black 3m ID 4mm flame retardant` |
| Braided PET Cable Sleeve | 1 | `AliExpress Mar 25 / 8210696713925240` | `Black 5m ID 4mm flame retardant` |
| Nylon Braid Sleeving Tight | 1 | `AliExpress Mar 25 / 8210696714075240` | `Black 5m 6mm flame retardant nylon` |
| M2 Hex Socket Cap Screw Set (482pcs) | 1 | `AliExpress Mar 25 / 8210696713905240` | `M2 DIN912 12.9 Allen 482pcs black` |
| PET Expandable Braided Sleeving | 1 | `AliExpress Mar 25 / 8210696713725240` | `Black 10m 2mm high density nylon mesh` |
| 1/4W Metal Film Resistor Kit (300pcs) | 1 | `AliExpress Mar 25 / 8210696713885240` | `300pcs 30 kinds 1% - 1K/10K/100K/220ohm/1M` |
| PTFE Thread Seal Tape 4M | 1 | `AliExpress Mar 25 / 8210696713705240` | `4M roll oil-free sealing tape` |
| Ceramic Capacitor 100nF 50V (100pcs) | 1 | `AliExpress Mar 25 / 8210696713865240` | `50V 100nF 0.1uF 104 100pcs` |
| TCS3200 GY-31 Color Sensor Module | 2 | `AliExpress Mar 25 / 8210696713785240` | `TCS230/TCS3200 color recognition module` |
| Biochemical Filter Foam Pad | 2 | `AliExpress Mar 25 / 8210696713765240` | `50x12x2cm 25PPI large hole black` |
| MR115ZZ Flanged Ball Bearing (10pcs) | 1 | `AliExpress Mar 25 / 8210696713585240` | `5x11x4mm MR115ZZ flanged 10pcs` |
| Neoprene Rubber Gasket Strip | 1 | `AliExpress Mar 25 / 8210696713565240` | `2000x19x3mm neoprene belt strip target` |
| Neoprene Rubber Gasket Strip | 1 | `AliExpress Mar 25 / 8210696713545240` | `2000x19x3mm neoprene belt strip backup` |
| Nylon Cable Ties (100pcs) | 1 | `AliExpress Mar 25 / 8210696714015240` | `Black 3x100mm 100pcs self-locking` |
| IR Break Beam Sensor (4 Pairs) | 2 | `AliExpress Mar 25 / 8210696713845240` | `3mm LED 3-5V DC 100cm 4 pairs per set` |
| NEMA17 Stepper Motor 17HS4401S | 1 | `AliExpress Mar 25 / 8210696713995240` | `42BYGH 1.5A 42N.cm 4-lead XH2.54 1pcs` |
| Inline Fuse Holder 18AWG (2pcs) | 1 | `AliExpress Mar 25 / 8210696713825240` | `Mini ATC/ATO 12V 5A 18AWG 2pcs` |
| PCB Prototype Board Double Sided (5pcs) | 1 | `AliExpress Mar 25 / 8210696713625240` | `5pcs 3x7cm blue double sided` |
| IRLZ44N N-Channel MOSFET TO-220 (10pcs) | 1 | `AliExpress Mar 25 / 8210696713605240` | `IRLZ44N TO-220 10pcs` |
| 0530 Linear Solenoid Electromagnet 12V | 3 | `AliExpress Mar 25 / 8210696714055240` | `0530 push/pull open frame DC 12V` |
| 608ZZ Deep Groove Ball Bearing (5pcs) | 1 | `AliExpress Mar 25 / 8210696714035240` | `8x22x7mm carbon steel 5pcs` |

Order total from spreadsheet: `$174.50`

## Still Needed And Not Yet Ordered

Current gap audit: use `SHORT_TODO.md`, `docs/ARCHITECTURE.md`, and current conveyor CAD assumptions as the buying gate. Do not carry forward old `docs/BOM.md` assumptions just because they sounded useful.

| Item | Classification | Why |
|---|---|-----|
| GT2 closed-loop timing belt, short | Needed now for next Amazon order | `100T`, `200mm`, `6mm` wide, `2mm` pitch. You confirmed you have no GT2 stock, and the current timing-stage geometry wants one install candidate plus one spare. |
| GT2 closed-loop timing belt, long | Needed now for next Amazon order | `104T`, `208mm`, `6mm` wide, `2mm` pitch. This is the second install candidate plus one spare around the modeled center distance. |
| GT2 motor pulley | Needed now for next Amazon order | `16T`, `5mm` bore, `6mm` belt width. Current architecture and `SHORT_TODO.md` call for this pulley pair, and you confirmed you have no GT2 hardware on hand. |
| GT2 driven pulley | Needed now for next Amazon order | `32T`, `5mm` bore, `6mm` belt width. One install plus one spare remains the cleanest way to preserve ratio flexibility. |
| Supported drive shaft | Needed now for next Amazon order | `5mm` precision shaft stock. You confirmed you have no shaft stock on hand, and the supported roller architecture requires it. |
| Shaft collars | Needed now for next Amazon order | `5mm` clamp shaft collars. You confirmed you have none on hand, and the supported shaft needs axial retention. |
| Separate belt tensioner hardware | Not actually needed under current architecture | Current plan is to use the slotted `NEMA17` mount first. Reopen only if packaging later proves the slot can not cover the adjustment range. |

No items currently fall into `Needed later but not urgent` for purchase planning. The remaining non-spreadsheet items that were previously listed as ordered are removed from the audit until a doc-backed need exists.

## Already Owned / Stock On Hand

| Part | Status |
|---|---|
| ESP32 DevKit | Present and functional |
| Breadboard and jumper wires | Present for bringup only |
| PLA filament | Confirmed at school printer |
| Soldering iron and solder | Present |
| LEGO bricks | 24 total: 6 red 2x2, 6 blue 2x2, 4 red 2x3, 8 blue 2x3 |
| LED indicator | Present |

## Spreadsheet Totals

| Source | Spreadsheet total |
|---|---|
| Amazon Mar 25 | `$149.52` |
| Amazon Mar 31 | `$62.87` |
| AliExpress Mar 25 | `$174.50` |
| **Grand total** | **`$386.89`** |

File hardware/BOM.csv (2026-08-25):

part | system_quantity | purpose | model_or_specification | authentic_source | procurement_record | notes
ESP32 development board | 1 | Main controller | Hosyond ESP32 USB-C CP2102 | BOM.xlsx | 3-pack purchased | Exact board revision not recorded
Stepper motor driver | 1 | Conveyor motor control | TMC2209 | BOM.xlsx | 3 purchased | Reference pin and microstep map retained under docs/datasheet
Stepper motor | 1 | Conveyor drive | NEMA17 17HS4401S 42BYGH 1.5 A 42 N.cm 4-lead XH2.54 | BOM.xlsx | 1 purchased | NEMA11 purchase omitted because it is not the final architecture
Servo | 1 | Rotary chute positioning | MG995 or MG996 class | BOM.md | Not in purchase workbook | Confirm exact installed model before attributing its reference geometry
Color sensor | 1 | Red and blue frequency sampling | TCS3200 GY-31 | BOM.xlsx | 2 purchased | Mounted in a light-blocking shroud
IR break-beam pair | 2 | Brick timing and length estimation | 3 mm emitter and receiver pair | BOM.xlsx | 2 sets of 4 pairs purchased | The archived 5 mm CAD does not match this purchase record
LiPo battery | 1 | Main power source | 3S 11.1 V 2200 mAh 50C XT60 | BOM.xlsx | 2-pack purchased | Validate pack condition before use
Buck converter | 1 | Regulated peripheral rail | LM2596 3.0-40 V input 1.5-35 V output | BOM.xlsx | 5-pack purchased | Set and verify output before connecting loads
Inline fuse holder | 1 | Battery input protection | Mini ATC or ATO 12 V 5 A 18 AWG | BOM.xlsx | 2-pack purchased | Confirm the fuse actually fitted to the machine
Bulk capacitor | 1 | Stepper input transient support | 4700 uF 25 V 16 x 25 mm electrolytic | BOM.xlsx | 10-pack purchased | Confirm polarity
GT2 belt and pulley set | 1 | Conveyor transmission | GT2 | BOM.md | Not in purchase workbook | Confirm installed lengths and bore sizes
MR85ZZ bearings | 1 set | Conveyor shaft support | 5 x 8 x 2.5 mm | BOM.xlsx | 10-pack purchased | Reference STEP retained under docs/datasheet
608ZZ bearings | 1 set | Roller support | 8 x 22 x 7 mm | BOM.xlsx | 5-pack purchased | Confirm installed count
Wood frame stock | 1 set | Machine structure | Final stock unspecified | BOM.md | Not in purchase workbook | Record final dimensions
Printed brackets and guides | 1 set | Mounting alignment and feed control | Project-specific printed parts | BOM.md | Not in purchase workbook | Editable CAD is not included
Printed shroud | 1 | Ambient-light control around color sensor | Project-specific printed part | BOM.md | Not in purchase workbook | Final geometry is not documented
Printed rotary chute | 1 | Route bricks into four bins | Project-specific printed part | BOM.md | Not in purchase workbook | Final geometry is not documented
Low-friction tape | 1 roll | Reduce chute drag | UHMW or PTFE tape | BOM.md | PTFE thread-seal tape appears in BOM.xlsx | Confirm the material actually installed
Black foam and electrical tape | 1 set | Light blocking and bounce control | Build material | BOM.md | Black foam purchased | Electrical tape purchase is not recorded
M3 mounting hardware | 1 set | Printed-part and electronics mounting | M3 fasteners | BOM.md | Not in purchase workbook | The workbook records an M2 kit instead; confirm final lengths and quantities
18 AWG red and black wire | 1 set | Power distribution | 25 ft per color stranded automotive wire | BOM.xlsx | 1 red-black pack purchased | Workbook specifies copper-clad aluminum; validate current capacity on the machine
Braided cable sleeve and cable ties | 1 set | Cable routing and strain management | 2 mm 4 mm and 6 mm PET or nylon sleeve plus 3 x 100 mm ties | BOM.xlsx | Multiple sleeve rolls and 100 ties purchased | Use only where clear of moving parts
XT60 pigtail | 1 | Battery connection | XT60 | BOM.md user-supplied addition | Outside purchase workbook | Confirm polarity before power-up
Lever connectors | 1 set | Power distribution | 5-port WAGO class | BOM.md user-supplied addition | Outside purchase workbook | Confirm current rating and installed model
Wood screws | 1 set | Frame and bracket fastening | Size unspecified | BOM.md user-supplied addition | Outside purchase workbook | Record installed sizes
Operator display | 1 | Planned status display | Waveshare 2 inch Mini LCD 240 x 320 ST7789VW SPI | BOM.xlsx | 1 purchased | Firmware display functions are currently log-only

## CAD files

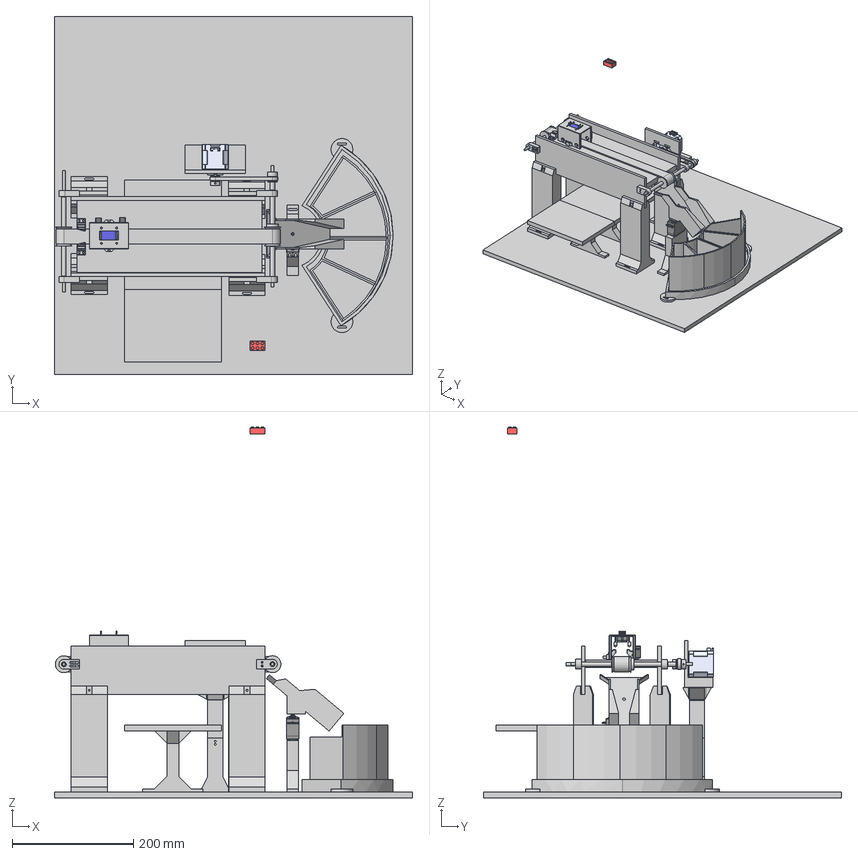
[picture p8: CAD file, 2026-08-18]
cad/exports/conveyor-assembly.step
590.0 x 590.0 x 611.0 mm

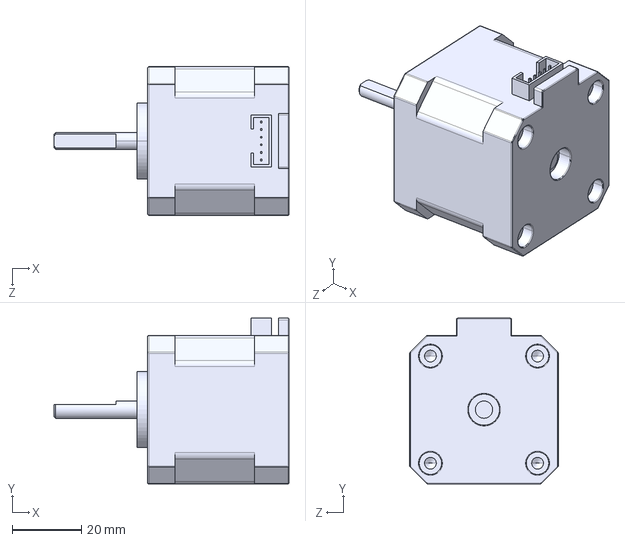
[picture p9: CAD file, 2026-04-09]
docs/datasheet/motion/nema17/cad/stepper_17hs4401s.step
68.0 x 48.0 x 43.0 mm

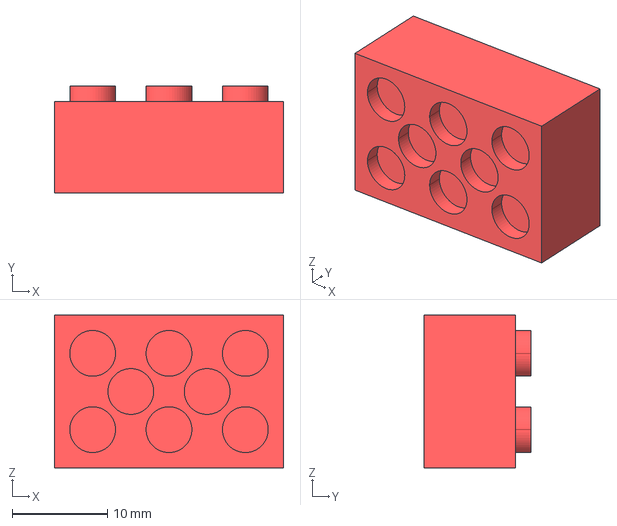
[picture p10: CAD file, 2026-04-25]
docs/datasheet/reference/lego_2x3/lego2x3_red.stp
24.0 x 11.2 x 16.0 mm

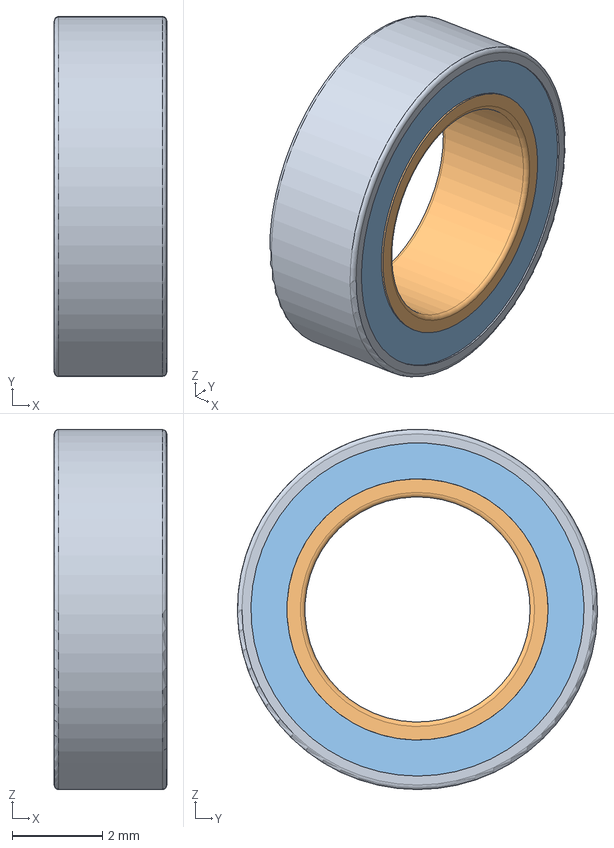
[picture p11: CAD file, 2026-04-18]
docs/datasheet/fasteners/bearing/cad/nsk_mr85zz.stp
2.50 x 8.00 x 8.00 mm
MR85ZZ Outer Ring
MR85ZZ Inner Ring
MR85ZZ Shield1
MR85ZZ Ball x 17
MR85ZZ Shield2

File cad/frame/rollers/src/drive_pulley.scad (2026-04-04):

include <rollers_params.scad>

module drive_pulley(params = default_params()) {
  validate(params);

  roller_od = pget(params, "provisional_drive_roller_od");
  face_w = pget(params, "provisional_contact_face_width");
  flange_w = pget(params, "provisional_flange_width");
  flange_od = pget(params, "provisional_flange_od");

  hub_od = pget(params, "provisional_drive_hub_od");
  hub_w = pget(params, "provisional_drive_hub_width");

  d_bore_round = pget(params, "provisional_d_bore_round");
  d_bore_to_flat = pget(params, "provisional_d_bore_to_flat");
  clamp_slot_w = pget(params, "provisional_split_clamp_slot");
  clamp_screw_axis_x = pget(params, "provisional_clamp_screw_axis_x");
  clamp_screw_d = pget(params, "provisional_clamp_screw_clear_d");
  clamp_screw_head_d = pget(params, "provisional_clamp_screw_head_d");
  clamp_screw_head_depth = pget(params, "provisional_clamp_screw_head_depth");
  clamp_nut_flat = pget(params, "provisional_clamp_nut_flat");
  clamp_nut_thickness = pget(params, "provisional_clamp_nut_thickness");

  total_w = face_w + (2 * flange_w);
  hub_start = (total_w - hub_w) / 2;

  difference() {
    union() {
      cylinder(h = flange_w, d = flange_od);
      translate([0, 0, flange_w])
        cylinder(h = face_w, d = roller_od);
      translate([0, 0, flange_w + face_w])
        cylinder(h = flange_w, d = flange_od);

      translate([0, 0, hub_start])
        cylinder(h = hub_w, d = hub_od);
    }

    translate([0, 0, -0.25])
      d_bore_cutout(total_w + 0.5, d_bore_round, d_bore_to_flat);

    translate([0, -clamp_slot_w / 2, -0.25])
      cube([hub_od, clamp_slot_w, total_w + 0.5]);

    translate([clamp_screw_axis_x, 0, total_w / 2])
      rotate([90, 0, 0])
        cylinder(h = hub_od + 2, d = clamp_screw_d, center = true);

    translate([clamp_screw_axis_x, -(hub_od / 2) + (clamp_screw_head_depth / 2), total_w / 2])
      rotate([90, 0, 0])
        cylinder(h = clamp_screw_head_depth + 0.4, d = clamp_screw_head_d, center = true);

    translate([clamp_screw_axis_x, (hub_od / 2) - (clamp_nut_thickness / 2), total_w / 2])
      rotate([90, 0, 0])
        cylinder(h = clamp_nut_thickness + 0.4, d = clamp_nut_flat / cos(30), center = true, $fn = 6);
  }
}

build_target = is_undef(build_target) ? "model" : build_target;
params = is_undef(params) ? default_params() : params;

if (build_target == "model") {
  drive_pulley(params);
} else if (build_target == "validate") {
  validate(params);
  dimension_report(params);
  cube([1, 1, 1]);
} else if (build_target == "report") {
  dimension_report(params);
  cube([1, 1, 1]);
} else {
  drive_pulley(params);
}

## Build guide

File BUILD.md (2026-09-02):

# Build, Wiring, and Calibration

This guide consolidates the active assembly, electrical, and calibration
instructions. Verify every dimension and connection against the physical
machine before applying power.

## Constraint-driven mechanical design

I worked outward from the ground-truth objects and components the sorter had to
handle. LEGO brick width and travel orientation constrained the usable belt
width and guide clearance. That conveyor envelope constrained the sensing
station and the chute mouth; the chute sweep then set the four-bin arc, spacing,
and required collection volume. The servo foot placed the chute at a reliable
drop point, which set the conveyor height, NEMA17 support height, and reserved
electronics-underbody envelope.

The CAD therefore formed one dependency chain:

```text
brick geometry -> belt/guides -> sensing + chute mouth -> bin arc/volume
               -> servo support -> conveyor height -> motor + electronics envelope
```

Major interfaces were aligned before fabrication, reducing unnecessary
reprints and assembly rework. Slots and extra clearance were retained at real
mounting interfaces so the physical system could absorb millimeter-scale build,
belt-tension, and placement error.

## Build progression

The first two to three weeks combined sketches, dimensional calculations,
component selection, ordering, and CAD with work on another project. Most
fabrication, electronics integration, firmware, calibration, and debugging then
landed in a concentrated final two-week sprint; the constraint chain above kept
that rapid assembly from becoming a sequence of avoidable reprints.

| 1. Frame and rollers | 2. Belt curing and alignment | 3. Electronics integration |
| --- | --- | --- |
| Wooden frame with 3D-printed conveyor rollers | Dumbbell holding the stapled and taped belt assembly while epoxy cures | Conveyor after wiring and electronics integration |
| Wooden boards and printed rollers establish the conveyor frame. | The dumbbell is used to cure the epoxy+staple joint | Tuning and integration phase after wiring |

## Mechanical assembly

### 1. Frame and conveyor

1. Build the frame within the event footprint limit.
2. Mount the conveyor side plates, shaft supports, and bearings.
3. Install the rollers, GT2 belt and pulleys, NEMA17 motor, and tensioning
   hardware.
4. Turn the system by hand and correct belt tracking or binding before power is
   connected.

### 2. Sensing station

1. Mount two break-beam pairs across the conveyor at a measured spacing.
2. Mount the TCS3200/GY-31 above the belt inside a light-blocking shroud.
3. Add low guides so each brick enters studs up and aligned with travel.
4. Confirm both beam transitions and all three color-filter readings over
   serial before continuing.

### Component fit checks

The following manual measurements from the April 2026 build notes were used as
fit checks during mechanical design:

| Component | Manual measurement | Build implication |
| --- | --- | --- |
| NEMA17 | 38.1 mm body; 20.54 mm observed shaft stickout; 5 mm D-shaft class | Verify the actual motor before cutting the mount: the retained supplier drawing shows a 23.5 +/- 0.5 mm shaft envelope, so the archived sources disagree. |
| TCS3200/GY-31 module | 33.34 x 33.34 mm board; 25.4 mm overall height including pins and LEDs | Leave shroud roof and underside pin clearance; do not dimension from the bare sensor package. |
| IR break-beam bodies | 19.05 mm long and 9.53 mm thick in the manual note | Check both sides of the shroud for body and cable clearance after setting the measured beam spacing. |
| TMC2209 carrier | 20.64 x 14.29 mm board; 23.81 mm overall height with pins and heatsink | Reserve vertical cooling and connector clearance around the driver carrier. |

The original NEMA17 supplier schematic, color-sensor module manual, and related
reference files are indexed in [docs/datasheet/README.md](docs/datasheet/README.md).
Earlier NEMA11 and solenoid measurements are not relevant to the final design.

### 3. Chute and bins

1. Rigidly mount the MG995/MG996-class servo at the belt exit.
2. Attach the rotary chute and check clearance through the full angle range.
3. Add a low-friction surface where needed.
4. Position and label the bins in firmware order: `2x2 RED`, `2x3 RED`,
   `2x3 BLUE`, `2x2 BLUE`.

## Electrical

I planned the power distribution and signal paths before physical wiring. The
design places a fuse immediately after the 3S LiPo, keeps the stepper driver on
the 12 V motor path, and uses buck conversion for the 5 V ESP32/peripheral path;
the fuse limits fault current while rail separation reduces the risk of
over-voltage damage to lower-voltage electronics.

| Power and system plan | Motor and sensor detail |
| --- | --- |
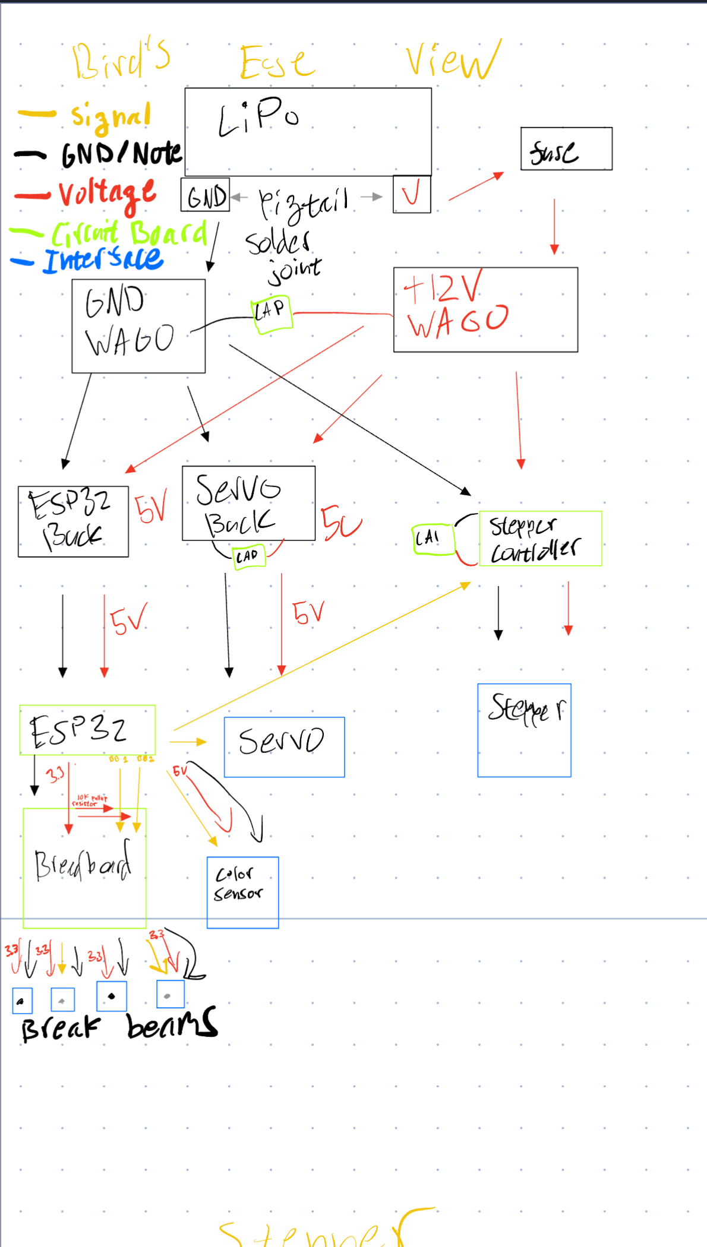
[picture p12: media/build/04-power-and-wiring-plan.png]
Hand-drawn pre-build power and signal wiring plan
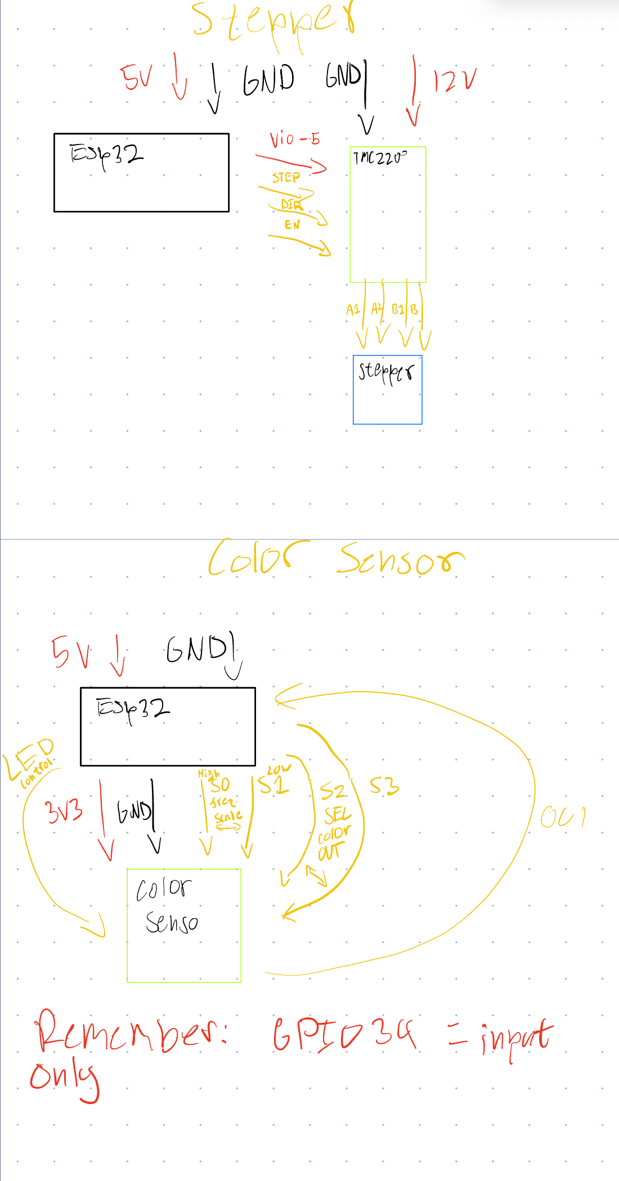
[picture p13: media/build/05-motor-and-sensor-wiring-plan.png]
Hand-drawn pre-build stepper and color-sensor wiring plan
|  |  |
| Fused input, voltage rails, controller, servo, stepper, color sensor, and break-beam paths. | Planned TMC2209/stepper and TCS3200 connections before assembly. |

These pre-build sketches capture the planned power and signal layout. Use the
current firmware pin map below and verify the physical machine before applying
power.

The design uses a fused 3S LiPo input, a motor rail for the stepper driver, a
buck-converted 5 V rail for suitable peripherals, and a common ground. Confirm
the real regulator rating, servo current path, fuse, wire gauge, polarity, and
grounding before connecting the battery.

### Firmware pin map

| Function | ESP32 GPIO | Notes |
| --- | ---: | --- |
| Conveyor STEP | 25 | LEDC-generated pulse output |
| Conveyor DIR | 27 | Forward/reverse level from `config.h` |
| Conveyor ENABLE | 26 | Active low; clamped disabled at startup |
| TMC UART | 23 | Reserved in configuration |
| Chute servo PWM | 32 | MG995/MG996-class servo |
| Break-beam A | 33 | Active-low input with pull-up |
| Break-beam B | 15 | Active-low input with pull-up |
| TCS3200 OUT | 34 | Input-only GPIO; external pull-up as required |
| TCS3200 S2 | 17 | Color-filter select |
| TCS3200 S3 | 18 | Color-filter select |
| Buzzer | 14 | Error indication |

The firmware comments specify that TCS3200 S0 is tied to 3.3 V, S1 to ground,
and OE to ground. GPIO 34 is input-only. Validate these choices against the
actual sensor board and wiring before use.

Pins 21/22 and PCF8574 address `0x20` remain reserved in configuration, but the
current display functions are log-only. Do not treat a display wiring plan as
implemented firmware.

## Firmware

Install PlatformIO, then build from the repository root:

```sh
cd firmware
pio run
pio run -e servo_tuning
```

To flash and monitor the main controller:

```sh
pio run -t upload
pio device monitor -b 115200
```

Use `firmware/tools/servo_tuning/` when centering the chute or establishing bin
angles. Copy confirmed angles into `firmware/tsa_sorter/config.h`, rebuild, and
repeat the physical clearance check.

## Calibration

Calibration is operator-assisted. The firmware stores values but does not fit
color or size thresholds from the recorded clusters.

### 1. Inspect defaults and capture the belt

With the final belt and shroud installed, open the serial monitor and run:

```text
cal show
cal belt 8
cal show
```

The belt capture averages valid red, blue, and clear readings for later
subtraction. If samples are invalid, correct lighting, alignment, or wiring
before proceeding.

### 2. Select the size threshold

1. Feed several 2x2 and 2x3 bricks at the intended conveyor setting.
2. Capture the serial output with `firmware/tools/capture_serial_log.sh` or a
   terminal logger.
3. Review measured length and skew; exclude physically explained outliers.
4. Choose a threshold that separates the stable clusters and enter it:

```text
set size <millimeters>
```

### 3. Select the color threshold

1. Record several moving red and blue passes with the shroud installed.
2. Review the belt-subtracted `red / (red + blue)` values.
3. Choose a separating threshold and enter it:

```text
set color <ratio>
```

### 4. Tune chute angles

1. Build and flash the `servo_tuning` environment.
2. Move to each bin position with commands `1` through `4`, or enter an angle
   from `0` to `180`.
3. Test with the longest supported brick and record the centered angle for each
   bin.
4. Update `config.h`, rebuild the main environment, and repeat the drops.

### 5. Save and verify

After reviewing all selected values:

```text
cal save
cal show
```

`cal save` persists the thresholds and belt baseline to ESP32 NVS. Use
`cal wipe` only when intentionally returning to the compiled defaults.

## Working demo and test workflow

[Watch the completed sorter run on YouTube](https://www.youtube.com/watch?v=zOtNFu6YxYQ). The final assembled-system photo is available
[here](media/final/sorter-final.jpg).

For a repeatable test session, use a consistent feed orientation and retain the
serial/CSV log alongside the selected calibration profile and speed mode. The
firmware helper at `firmware/tools/capture_serial_log.sh` records the serial
output for later review.

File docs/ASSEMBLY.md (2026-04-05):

# Full System Assembly Guide

This is the primary assembly guide for the complete sorter.

Audience:
- A beginner builder
- A teammate who did not design every part
- A first-time operator preparing the machine for validation

Use this guide with:
- `docs/ARCHITECTURE.md`
- `cad/DIMENSIONS.md`
- `cad/MECHANICAL.md`
- `wiring/ELECTRICAL.md`
- `docs/CHECKLIST.md`
- `docs/CALIBRATION.md`

## Safety and hard rules

1. Use LiPo power for any meaningful run.
2. Do not skip flyback diodes on solenoids.
3. Do not skip bulk capacitors at the stepper driver motor inputs.
4. Keep total footprint at or below 610mm by 610mm.
5. Keep bricks widthwise across the conveyor.
6. Calibrate color sensing only with the shroud installed.

## What this machine does

The system sorts 24 LEGO bricks into 4 bins by size and color.

Pipeline summary:
1. Bricks start preloaded in a compressed queue.
2. One brick enters the chamber and seats at the stop wall.
3. Belt stops.
4. Size and color sensing happen while static.
5. Selector chute indexes to the target bin.
6. Trapdoor removes support and the brick falls.
7. Bin confirmation verifies arrival.
8. Platform returns level.
9. Next brick advances by chamber pitch after reset truth is satisfied.

## Build sequence

Follow this order.

1. Chute transition validation
2. Conveyor packaging and interface lock
3. Trapdoor gate parts and cycle test
4. Chamber sensing geometry fit
5. Selector chute alignment and routing-cost study
6. Bin and drop-path fit check
7. Full mechanical packaging and labels
8. Wiring and power checks
9. Calibration
10. Full 24-brick reliability runs

## Stage 1: Chute transition first

Goal:
- Prove reliable feed before broader printing

Steps:
1. Print chute transition prototype only.
2. Deburr and smooth contact surfaces.
3. Feed real bricks under expected stack load.
4. Verify no jam and no double-feed behavior.

Pass criteria:
- Zero jams in 50 feed attempts
- Zero double-feed events in 50 feed attempts

## Stage 2: Conveyor packaging and interface lock

Goal:
- Lock the production conveyor path before chamber and frame work drift

The active conveyor path is:
- NEMA17 motor
- Toothed timing-belt stage
- Supported drive roller shaft
- Smooth drive roller
- Neoprene conveyor belt

Steps:
1. Run roller and fit coupons first.
2. Package the motor, pulleys, belt envelope, supported shaft, bearings, idler, and tension adjust travel.
3. Confirm chamber interface height and belt plane.
4. Confirm service access, belt guard clearance, and cable-routing path.
5. Confirm footprint impact before printing larger structural parts.

Pass criteria:
- No hard interference in packaging CAD
- Shaft support and tension ranges documented
- Conveyor module fits the full-system envelope with margin

## Stage 3: Trapdoor mechanism gate

Parts:
- Platform
- Hinge bracket
- Lever arm
- Lever pivot bracket
- Solenoid bracket

Steps:
1. Assemble hinge with 3mm rod.
2. Verify free platform pivot.
3. Install lever and pivot fastener.
4. Verify lever tip engages the platform tab at rest.
5. Install solenoid and return springs.
6. Trigger repeated loaded release cycles.

Pass criteria:
- Zero failed drops in 50 loaded cycles
- Zero failed re-latch cycles in 50 loaded cycles
- Return to level under target timing

## Stage 4: Chamber sensing fit

Goal:
- Freeze chamber interfaces before wiring is finalized

Steps:
1. Print chamber fit parts.
2. Fit size beam mounts at target chamber positions.
3. Fit color sensor window and shroud.
4. Install stop switch and verify actuator travel.
5. Verify platform-level sensing path if used.
6. Insert real bricks and check motion clearance.

Pass criteria:
- No forced sensor fit
- No light leaks around the shroud
- No brick obstruction during seat or release

## Stage 5: Selector chute alignment and routing study

Goal:
- Guarantee a clean drop path and quantify selector cost honestly

Steps:
1. Print selector chute prototype.
2. Mount on 5mm aluminum hub.
3. Mount to the stepper and homing hardware.
4. Cycle each selector position.
5. Perform repeated drop tests per bin.
6. Record adjacent, worst-case, and weighted selector motion cost for the real brick mix.

Pass criteria:
- Clean path in all four positions
- No edge catch in at least 25 drops per bin
- Selector gate study created for the notebook

## Stage 6: Bins, labels, and operator UX

Install and verify:
1. Bin labels:
- 2x2 RED
- 2x2 BLUE
- 2x3 BLUE
- 2x3 RED
2. Start control label
3. Display states:
- READY
- SORTING
- SORT COMPLETE
- ERROR
4. Orientation cue at chute entrance:
- studs up
- length along travel axis
5. Cable routing and strain relief

Goal:
- A first-time evaluator can operate the system without assistance

## Stage 7: Wiring and power integration

Follow `wiring/ELECTRICAL.md`.

Checklist:
1. Common ground across logic and actuator rails
2. Flyback diode polarity on the solenoid path
3. Stepper motor-input bulk capacitors installed
4. Safe wire routing away from moving parts
5. Strain relief at moving interfaces

Pre-power checks:
1. No short between rails
2. Correct connector pinouts
3. MOSFET orientation verified
4. Home, stop, and reset-related sensors actuate correctly

## Stage 8: Calibration

Follow `docs/CALIBRATION.md`.

Order:
1. Lever release calibration
2. Chamber seat and pitch-advance timing calibration
3. Color threshold calibration with shroud installed
4. Selector timing and routing study
5. Full-system validation runs

Data rule:
- Keep run data in CSV logs for notebook use

## Stage 9: Full-run acceptance

Before calling the system ready:
1. Run at least 10 complete 24-brick sets.
2. Log all failures by type and stage.
3. Confirm repeatability, not just one successful run.
4. Verify packaging and footprint compliance again.
5. Verify the selector evidence gate decision is recorded.

## Common build mistakes and fixes

Belt walks sideways:
- Check roller parallel alignment.
- Reduce over-tension.
- Confirm crown orientation and quality.

Lever fails to re-latch:
- Check tip and tab chamfer contact.
- Check return spring preload.
- Check pivot friction and binding.

Color classification unstable:
- Confirm the shroud is installed.
- Recalibrate threshold from fresh sample windows.
- Shield color sensor wiring from motor wiring.

Chute feed jams:
- Reinspect transition geometry.
- Verify printed clearances with calipers.
- Smooth friction points.

## Where to put subsystem assembly guides

Use this pattern:
1. `docs/ASSEMBLY.md` for full-system workflow
2. Subsystem assembly guides in subsystem folders

Current subsystem guide:
- `cad/frame/rollers/ASSEMBLY.md`

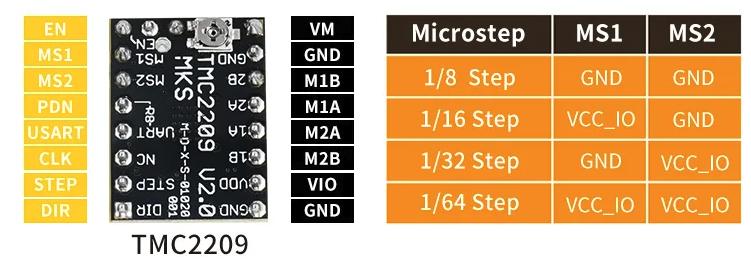
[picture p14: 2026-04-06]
docs/datasheet/electrical/stepper_driver/images/wiring.png

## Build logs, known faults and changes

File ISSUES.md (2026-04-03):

# Open Issues

Unresolved technical questions, decisions, and logistics that need to be addressed before specific build phases. Not the same as risks (those are in ARCHITECTURE.md) -- these are specific open items with a resolution path.

---

## Before frame CAD (before April 2)

**Top-down footprint layout**
Draw a to-scale top-down view of the full system: belt, bins, chute footprint, frame edges. Verify everything fits within 610mm x 610mm. This is a 30-minute task. Do not start frame CAD without it. Bins diverting sideways are the main unknown -- two bins per side, each ~80mm wide x 100mm deep, need to confirm they fit alongside the belt run.

**Exact bin positions**
The exact distance from the sensing zone to each of the 4 bin entrance beams is needed for:
1. PI controller Option B (transit time / distance = speed)
2. Solenoid de-energize timing (currently estimated at 280ms, needs actual measurement)
3. Bin confirmation timeout (currently 500ms estimate, needs to be set from measured transit times)

Determine these in dry assembly. Log them. Update EMBEDDED.md and ELECTRICAL.md with actual values.

---

## During sensor validation (early April)

**Belt speed at operating voltage**
The TT gearmotor spec gives a no-load RPM. Actual belt speed under load at 5V with the selected PWM duty cycle is not known. Measure it during breadboard validation (run motor, manually time a brick over a known distance). If actual speed differs significantly from 200mm/s, recalculate: size detection threshold, solenoid de-energize timing, color dwell time, brick spacing.

**Belt friction with bricks**
Verify bricks do not slide sideways on the smooth GT2 belt surface during plow actuation. The plow tip pushes laterally against a moving brick -- if belt-to-brick friction is too low, the brick may spin rather than deflect cleanly. Test during first powered belt run. If sliding is a problem, lightly textured belt surface or slightly slowing the belt during plow contact are options.

**L298N PWM frequency**
Test at 1kHz, 5kHz, and 10kHz. Observe: motor response, audible noise, L298N temperature under sustained operation. Pick the frequency that gives smooth control with acceptable heat. Document the result.

**LiPo capacity under load**
Run 5 back-to-back full 24-brick runs and note voltage at start and end. Estimate how many runs a full charge supports. Competition may involve 3-5 judge demo requests in sequence. If one charge cannot cover a session, plan a charging break or verify the second LiPo can be swapped quickly.

---

## During integration (April 9-14)

**I2C stability under load**
If color sensor drops reads when belt motor and solenoids are active (EMI, ground noise), add 4.7k pullup resistors on SDA and SCL. Diagnose before assuming the sensor is broken.

**Timer allocation on ESP32**
Track which hardware timers are used as firmware is written. ESP32 has 4 hardware timers. Minimum needed: 1 for size detection, 1 for solenoid scheduling. The pulse counter peripheral handles encoder counting separately. Leave at least 1 timer unallocated as reserve.

---

## Competition power source (resolve before ordering second LiPo)

**AC outlet availability at the judging table**
The scoring does not require battery power. A bench supply at competition is more reliable than LiPo -- no voltage sag, no depletion across back-to-back demos, simpler two-rail isolation. But it requires AC power at the judging table, which is not guaranteed at TSA state/nationals venues.

Resolution path: contact event organizers or find a past competitor who can confirm whether outlets are available at individual judging stations. If yes, use a bench supply for competition and skip the second LiPo. If no or unknown, stick with LiPo.

Either way, use the bench supply for all development and calibration.

## Competition logistics (before April 29)

**Reload time**
Practice reloading 24 bricks from bins back into the chute in under 30 seconds. Judges may request a second immediate demo. The 20-second load estimate assumes smooth operation. Practice this as a deliberate drill, not an afterthought.

**Error recovery procedure**
If the system halts on ERROR_HALT during a judge demo: know exactly what to do. The procedure should be: identify the jammed brick, clear it, reset the system, reload as needed. Walk through this scenario at least twice before competition so it looks practiced, not panicked.

**Laptop for serial monitor**
Bring a laptop configured to open serial immediately. During demo, serial output shows internal state which can answer judge questions in real time ("what did it classify that brick as?"). Also useful for diagnosing any unexpected behavior.

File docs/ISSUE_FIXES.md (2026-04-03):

# Issue Fix Analysis

Pre-order review. No redesign. Minimal changes only.

---

## ISSUE 1: Size beam brick positioning

### STEP 1: Root Cause

The single IR break-beam crosses the 22mm chute dimension (Y axis) at X = 20mm
along the 27mm dimension. Detection logic: beam blocked = 2x3, beam clear = 2x2.

A 2x3 brick (23.7mm along X) always blocks the beam regardless of position. The
brick has only 3.3mm of play in 27mm, and even at worst case (P = 3.3mm from
reference wall), its far edge is at 27mm, well past the beam at 20mm.

A 2x2 brick (15.8mm along X) has 11.2mm of play in 27mm. The brick blocks the
beam only when its far edge exceeds X = 20mm, i.e., when its near edge P < 4.2mm.

    P ranges from 0 to 11.2mm.
    Safe zone (beam clear, correct detection): P in [0, 4.2] = 4.2mm range.
    Failure zone (beam blocked, false 2x3): P in [4.2, 11.2] = 7.0mm range.
    Failure rate: 7.0 / 11.2 = 62.5% of the time, IF brick position is random.

Nothing in the documentation constrains the brick's X position on the cam chord.
The cam chord is a flat surface. The brick drops from the stack above. No spring,
ramp, ledge, or asymmetry biases it toward the reference wall.

A tilted chord does not fix this. Gravitational force on a 3g brick at 10 degrees:
F_parallel = 0.003 * 9.81 * sin(10) = 5.1 mN. Static friction on PLA at mu = 0.4:
F_friction = 0.003 * 9.81 * cos(10) * 0.4 = 11.6 mN. Friction exceeds gravity at
any practical tilt angle. The brick does not slide.

### STEP 2: Minimal Fix

Add a second IR break-beam in the chute. Space the two beams so that a 2x2 brick
(15.8mm) can never span both simultaneously, but a 2x3 brick (23.7mm) always spans
both.

Required: beam spacing > 15.8mm (2x2 cannot bridge the gap).
Required: both beams within the 2x3 brick's guaranteed footprint at any position.

Beam positions: X = 5mm and X = 21mm from reference wall. Spacing = 16mm.

Verification (all numbers computed, see appendix A):

    2x3 brick, all positions (P = 0 to 3.3mm):
      Beam 1 (X=5):  P <= 3.3 < 5 < 3.3 + 23.7 = 27.  Always blocked.
      Beam 2 (X=21): P <= 3.3 < 21 < 27.               Always blocked.
      Result: always (blocked, blocked).

    2x2 brick, all positions (P = 0 to 11.2mm):
      Beam 1 (X=5):  blocked when P <= 5.  Range: [0, 5].
      Beam 2 (X=21): blocked when P >= 21 - 15.8 = 5.2.  Range: [5.2, 11.2].
      Both blocked: requires P <= 5 AND P >= 5.2.  NO OVERLAP.
      Result: never (blocked, blocked).

Detection logic change in firmware:

    if (beam1_blocked AND beam2_blocked): size = SIZE_2x3
    else: size = SIZE_2x2

Zero ambiguity. No dependence on brick position. No dependence on belt speed.
No additional mechanical positioning mechanism needed.

Parts impact: one additional IR break-beam pair (from the existing 2-spare pool;
reduces spare from 2 to 1). One additional GPIO pin on ESP32. Two additional 3mm
holes in the chute walls at X = 5mm (beam 1) and X = 21mm (beam 2, replaces the
original beam at X = 20mm).

The existing beam at X = 20mm moves to X = 21mm (1mm shift).

### Chord depth must increase

The beams pass through the chute above the cam chord surface, where the chord cut
has removed disk material. Both beams must be within the chord width. The chord
width depends on chord depth:

    Disk radius: 15mm.
    Chord width = 2 * sqrt(R^2 - (R - depth)^2)

    depth=2mm:  width=14.97mm, edges at X=6.02 to X=20.98.
      Beam X=5:  OUTSIDE chord by 1.02mm. Blocked by disk body.
      Beam X=21: OUTSIDE chord by 0.02mm. Blocked by disk body.
      FAILS.

    depth=4mm:  width=20.40mm, edges at X=3.30 to X=23.70.
      Beam X=5:  1.70mm inside chord edge.
      Beam X=21: 2.70mm inside chord edge.
      PASSES.

    depth=5mm:  width=22.36mm, edges at X=2.32 to X=24.68.
      Beam X=5:  2.68mm inside chord edge.
      Beam X=21: 3.68mm inside chord edge.
      PASSES with more margin.

At 2mm chord depth, the single-beam design barely works (X=20 beam is 0.98mm
inside the chord edge, equivalent to 3 FDM layer widths of margin). At 4mm depth,
both dual beams fit with comfortable margin.

Recommended chord depth: 4mm. This gives a chord width of 20.4mm, which aligns
with the documented "chord width: 20mm" in DIMENSIONS.md. The documented 2mm
depth was inconsistent with the documented 20mm width (a 2mm-deep chord on a
30mm disk is 15mm wide, not 20mm).

This resolves the DIMENSIONS.md chord conflict as a side effect.

### Beam Z-height constraint

Both beams must be above the disk material (within the chord-cut pocket) and
within the brick height (11.4mm above chord surface).

At beam X=5 (offset -8.5mm from disk center), with 4mm chord depth:
  Disk top at this X: sqrt(225 - 72.25) = 12.36mm from disk center.
  Chord flat: 11mm from disk center.
  Crescent (disk material above chord): 12.36 - 11 = 1.36mm.
  
Beam center at 5mm above chord (middle of brick): disk top is 1.36mm
above chord. Beam bottom edge at 3.5mm above chord. That is 2.14mm above
the disk crescent. Clear.

At beam X=21 (offset +7.5mm):
  Disk top: sqrt(225 - 56.25) = 12.99mm. Crescent: 1.99mm.
  Beam bottom at 3.5mm above chord: 1.51mm above crescent. Clear.

Both beams clear the disk body at 5mm above chord. Mount both emitter/receiver
pairs at this height relative to the chord surface.

### STEP 3: Risk Check

New risks introduced:

1. One fewer spare beam pair (from 2 to 1). Acceptable. If a beam fails at
   competition, swap from the spare.

2. Uses one additional GPIO pin. ESP32 has available pins. GPIO 36 and 39 are
   excluded per ELECTRICAL.md (phantom interrupt errata). Other input-capable
   pins are available (e.g., GPIO 39 could be used IF ADC1 is not active, or
   use any remaining strapping-safe pin). Must assign in config.h.

3. The 4mm chord depth means the chord is 2mm deeper than the original 2mm spec.
   The brick sits 2mm lower relative to the disk center. The exit ramp starting
   height shifts down by 2mm. Adjust shaft height or ramp geometry in CAD.

4. The 0.2mm gap between beam-1-blocked and beam-2-blocked zones (P = 5.0 to
   5.2mm) creates a narrow region where a 2x2 brick partially blocks both beams.
   Partial blockage (1.5mm of a 3mm beam) is below typical digital receiver
   thresholds. In practice this reads as (clear, clear) = 2x2. If concerned,
   shift beam 2 to X=21.5 (spacing 16.5mm, gap increases to 0.7mm).

### STEP 4: Compatibility Check

Geometry: beams at X=5 and X=21 fit within the 27mm chute dimension. Both
beams are 3mm diameter holes through the 27mm-wide chute walls. Separated by
16mm along X. No interference with each other or with the color sensor window
(which is in the same walls but at a different X position offset from the beams;
exact position determined in CAD per the existing note).

Sensor alignment: both beams cross the same 22mm Y dimension at the same Z
height (5mm above chord). Detection is binary digital. No analog sensitivity.

Motion paths: the beams are in the chute at cam level. The cam rotates in the XZ
plane (see Issue 2 resolution). During the dwell phase when sensing occurs, the
chord pocket is facing up, and both beams pass through open air above the chord.
During rotation (no sensing), the disk body may sweep through beam paths. This is
irrelevant since no readings are taken during rotation.

Tight zones: the 22mm Y cross-section is unchanged. The 27mm X dimension is
unchanged. The beams add two 3mm holes per wall. No structural concerns on 3mm
PLA walls.

### STEP 5: Final Decision

FIX ACCEPTED.

Changes:
  - Add one IR break-beam pair at chute X = 5mm (new beam 1).
  - Move existing beam from X = 20mm to X = 21mm (beam 2).
  - Increase cam chord depth from 2mm to 4mm in cam disk CAD.
  - Assign one GPIO pin for beam 1 in config.h.
  - Firmware: change detection from single-beam to dual-beam logic.
  - Adjust shaft Z position or ramp angle to compensate for 2mm lower chord.

No new parts needed (spare beam pair available in the existing order).

---

## ISSUE 2: Cam shaft orientation contradiction

### STEP 1: Root Cause

DIMENSIONS.md and CAD CLAUDE.md state: "Cam shaft hole: 5mm diameter, centered
in one 22mm face (perpendicular to belt travel)."

A "22mm face" is a chute wall that is 22mm wide and spans the Y dimension. This
wall is perpendicular to X (belt travel direction). If the shaft is through this
wall, the shaft axis is along X, and the cam disk rotates in the YZ plane.

MECHANICAL.md states: "The cam pushes the bottom brick horizontally out of the
chute onto a 10mm ramp." And the exit opening is described as being in the
"opposite 22mm face."

A cam rotating in YZ sweeps its lobe in Y and Z. It cannot push a brick along X
through an exit opening in a face perpendicular to X.

The only mechanically consistent interpretation: the shaft is along Y (through the
27mm-wide walls), and the cam rotates in XZ. The lobe sweeps along X and pushes
the brick through the exit opening in the opposite 27mm-wide wall.

"Centered in one 22mm face" should read "centered in one 27mm face." This is a
documentation labeling error.

### STEP 2: Minimal Fix

Correct the documentation. No physical design change. The mechanism was always
intended to work with the shaft along Y.

In DIMENSIONS.md, change:
  "Shaft bore: 5mm (NEMA 11 shaft)" is fine (dimension is correct).
  The shaft location description needs correction.

In CAD CLAUDE.md, change:
  "Cam shaft hole: 5mm diameter, centered in one 22mm face (perpendicular to
  belt travel)" to "Cam shaft hole: 5mm diameter, centered in one 27mm face
  (parallel to belt travel direction), with the shaft axis crossing the 22mm
  width."

Also correct the chord dimensions to resolve the 2mm/20mm inconsistency:
  "Chord depth: 4mm" (was 2mm)
  "Chord width: 20.4mm" (was 20mm, now geometrically consistent)

### STEP 3: Risk Check

Zero new risks. This is a documentation correction only. The physical design
was always correct in the engineers' mental model; the written description was
inconsistent.

### STEP 4: Compatibility Check

No physical changes. All downstream references to the cam shaft (NEMA 11 mount,
stepper wiring, TMC2209 configuration) are unaffected by the shaft location
correction. The shaft diameter (5mm) and motor specs are unchanged.

### STEP 5: Final Decision

FIX ACCEPTED.

Changes:
  - Update shaft location description in DIMENSIONS.md and CAD CLAUDE.md.
  - Update chord depth from 2mm to 4mm in DIMENSIONS.md (aligns with Issue 1 fix
    and resolves the documented 20mm-width inconsistency).

---

## ISSUE 3: Solenoid push geometrically marginal

### STEP 1: Root Cause

The original audit found that a 10mm solenoid stroke pushes the brick 3.8mm past
the channel wall, but the brick's center of gravity remains 4.1mm inside the
channel. The audit concluded the brick "relies on belt momentum" to complete the
exit.

This root cause analysis was INCORRECT. It treated the solenoid push as a static
displacement problem (where does the brick end up after 10mm of push) rather than
a dynamics problem (how fast is the brick moving after 10mm of push).

### STEP 2: Reassessment (not a fix, issue is retracted)

JF-0530B solenoid specs (from multiple vendor listings, confirmed):
  - Force: 5N at 10mm stroke (maximum, at end of stroke)
  - Available in 6V, 12V, 24V variants
  - Body: 30 x 16 x 15mm, push-pull type with return spring

Solenoid force varies with plunger position. At the START of stroke (10mm out),
force is lowest. At END (0mm, plunger fully retracted), force is maximum (5N).
Conservative start-of-stroke estimate for 6V variant: 1N.

A 2x3 LEGO brick weighs approximately 3 grams (0.003 kg).

At F = 1N (conservative), brick mass = 3g:
  Acceleration: 333 m/s2 (34g)
  Lateral velocity after 10mm of solenoid travel: 2582 mm/s
  Time to traverse 10mm stroke: 7.7 ms
  Time for brick to travel the remaining 12mm to clear channel: 4.6 ms
  Forward drift at 200mm/s belt speed during that 4.6 ms: 0.9 mm
  Bin opening: 30mm along belt axis.
  Forward drift (0.9mm) is 3% of the bin opening. Trivially clears.

At F = 0.5N (extremely conservative):
  Lateral velocity: 1826 mm/s
  Time to clear channel: 6.6 ms
  Forward drift: 1.3 mm. Still 4% of bin opening.

At F = 5N (rated maximum):
  Lateral velocity: 5774 mm/s
  Time to clear: 2.1 ms
  Forward drift: 0.4 mm.

The solenoid force exceeds the force needed to move the brick by a factor of
57x to 283x (depending on force estimate vs friction force of 0.018N). The brick
is effectively launched out of the channel at a lateral velocity of 1.8 to 5.8
meters per second. Belt speed is irrelevant to exit completion. The brick does
NOT "rely on belt momentum."

The original audit's static-displacement analysis was misleading because it
treated the problem as "where does the brick end up after being pushed 10mm"
rather than "what velocity does the brick have after being accelerated by 1-5N
over 10mm."

### STEP 3: Risk Check (of retraction)

Retaining the direct pusher design introduces no new risks. The design is
unchanged.

One thing worth noting: the brick exits at very high lateral velocity
(1800-5800 mm/s). This is 9-29x the belt speed. The brick trajectory is
nearly perpendicular to the belt. Bin ramp angle (10 degrees toward back wall)
is important for catching the brick. If the brick hits the back wall hard, it
could bounce. The 10-degree floor ramp helps, but at 5800 mm/s, the kinetic
energy of a 3g brick is 0.5 * 0.003 * 5.774^2 = 0.050 J. This is very small.
A PLA wall absorbs this easily. No bounce concern.

### STEP 4: Compatibility Check

No changes to the design. All existing geometry, firmware, and wiring are
unaffected.

### STEP 5: Final Decision

ISSUE RETRACTED. The 10mm direct pusher is not marginal. It is massively
over-specified for a 2-3 gram brick. No fix needed. Do not go back to the
solenoid plow.

---

## Answer: Should you go back to solenoid plow?

No. The direct pusher is the correct choice. The concern that motivated the plow
design (10mm stroke might not be enough) is invalid. The JF-0530B at 6V applies
enough force to launch a 3g brick laterally at nearly 2 meters per second through
10mm of stroke. The brick clears the channel in under 7ms with less than 2mm of
forward drift. Belt speed has negligible effect on exit reliability.

The plow (lever arm, pivot, spring calibration) adds fabrication complexity and
failure modes with zero functional benefit. Do not revisit.

---

## Answer: What to do about size detection

Add a second beam in the chute. Do not move sensing to the conveyor. Do not tilt.

Why dual beams in the chute:

  The dual-beam approach at X=5 and X=21 (spacing 16mm > 15.8mm brick width)
  gives zero-ambiguity detection regardless of brick position. It preserves the
  stationary-sensing architecture (no speed dependency, no timing measurement).

Why not move to conveyor:

  Belt-mounted dual beams require timing-based measurement. The firmware measures
  the time gap between beam 1 and beam 2 breaking, and infers brick length from
  belt speed. This reintroduces dependence on belt speed accuracy. If the PID loop
  has a transient error, the size measurement drifts. The current architecture
  deliberately eliminated this dependency by sensing while the brick is stationary.
  Moving to the conveyor is a step backward.

Why not tilt:

  For a 3g brick on PLA: static friction force = 11.6mN. Gravitational component
  at 10 degrees = 5.1mN. Friction exceeds gravity. The brick does not slide.
  Even at 20 degrees: gravity = 10.1mN, friction = 11.0mN. Still marginal. And
  20 degrees of chute tilt creates significant mechanical complications (exit ramp
  alignment, cam axis orientation, chute-to-belt transition geometry).

---

## Summary of all changes

| Change | Type | Parts impact | Firmware impact | CAD impact |
|---|---|---|---|---|
| Add beam at chute X=5mm | New component | Use 1 spare beam pair | Add GPIO, dual-beam logic | Two 3mm holes in chute walls |
| Move beam from X=20 to X=21 | Modification | None | Update beam position constant | Move existing hole 1mm |
| Chord depth 2mm to 4mm | CAD correction | None | None | Remodel cam disk chord |
| Update DIMENSIONS.md chord values | Documentation | None | None | None |
| Correct shaft wall label 22mm to 27mm | Documentation | None | None | None |
| Adjust shaft Z or ramp for 2mm lower chord | CAD adjustment | None | None | Minor ramp/mount change |

No new parts to order. No subsystem changes. No architecture changes.

---

## Appendix A: Dual beam detection matrix (exhaustive)

Beam 1: X = 5mm.  Beam 2: X = 21mm.  Spacing: 16mm.

2x3 brick (23.7mm), play 3.3mm:

| Brick near edge P | Beam 1 (X=5) | Beam 2 (X=21) | Reading | Correct? |
|---|---|---|---|---|
| 0.0 | blocked | blocked | 2x3 | YES |
| 1.0 | blocked | blocked | 2x3 | YES |
| 2.0 | blocked | blocked | 2x3 | YES |
| 3.3 (max) | blocked | blocked | 2x3 | YES |

2x2 brick (15.8mm), play 11.2mm:

| Brick near edge P | Beam 1 (X=5) | Beam 2 (X=21) | Reading | Correct? |
|---|---|---|---|---|
| 0.0 | blocked | clear | 2x2 | YES |
| 2.0 | blocked | clear | 2x2 | YES |
| 4.0 | blocked | clear | 2x2 | YES |
| 5.0 | edge | clear | 2x2 | YES |
| 5.1 | clear | clear | 2x2 | YES |
| 5.2 | clear | edge | 2x2 | YES |
| 6.0 | clear | blocked | 2x2 | YES |
| 8.0 | clear | blocked | 2x2 | YES |
| 11.2 (max) | clear | blocked | 2x2 | YES |

Decision rule: both blocked = 2x3. Anything else = 2x2.
100% correct at every possible position.

---

## Appendix B: Chord geometry at 4mm depth

    Disk radius: 15mm
    Chord depth: 4mm (from disk circumference)
    Chord distance from center: 15 - 4 = 11mm
    Chord half-width: sqrt(225 - 121) = sqrt(104) = 10.20mm
    Chord full width: 20.40mm
    Chord edges (in chute coords): X = 13.5 - 10.20 = 3.30 to X = 13.5 + 10.20 = 23.70

    Beam 1 at X=5: offset from center = -8.5mm. Inside chord by 1.70mm.
    Beam 2 at X=21: offset from center = +7.5mm. Inside chord by 2.70mm.

    Disk body height above chord at beam 1 (X=5):
      Disk top = sqrt(225 - 72.25) = 12.36mm from center.
      Chord = 11mm from center. Crescent = 1.36mm.
      Beam at 5mm above chord: 3.64mm above disk top. Clear.

    Disk body height above chord at beam 2 (X=21):
      Disk top = sqrt(225 - 56.25) = 12.99mm from center.
      Chord = 11mm. Crescent = 1.99mm.
      Beam at 5mm above chord: 3.01mm above disk top. Clear.

---

## ISSUE 4: Issue 1 and Issue 2 fixes not propagated to subsystem docs

### STEP 1: Root Cause

Issues 1 and 2 were accepted. Neither fix has been applied to the subsystem docs. Every
file below still contains the old values and will contradict the accepted changes. A builder
following any of these files would build to the wrong spec.

Stale values by file:

ARCHITECTURE.md:
  Line: "Single IR break-beam crosses the 27mm chute dimension at 20mm from the wall."
  Should describe dual beams at X=5 and X=21.

MECHANICAL.md (Sensing section, ~line 119):
  "Single IR break-beam crosses the 27mm chute dimension at 20mm from the reference wall.
   Emitter in one wall, receiver in the opposite wall."
  "Gap between brick sizes at beam position: 4.2mm on each side of threshold. Very robust."
  All three lines are obsolete. The gap claim no longer applies; the dual-beam design is
  position-independent.

MECHANICAL.md (Escapement section, ~line 44):
  "Flat chord (2mm depth) on the disk body where the bottom brick rests"
  Should be 4mm depth.

DIMENSIONS.md:
  "Chord depth (flat seat): 2mm" -> 4mm
  "Chord width: 20mm (centered)" -> 20.4mm (geometrically consistent with 4mm depth)
  "Size beam position (in 27mm dim): 20mm from reference wall"
  -> Two beams: 5mm and 21mm from reference wall

CALIBRATION.md (Notes section, last paragraph):
  "Size sensing needs no calibration. It is a single digital read (beam blocked or not).
   The only check is physical: verify a 2x3 brick blocks the beam and a 2x2 does not."
  The procedure description is still correct (no calibration needed, just physical
  verification), but "single digital read" and "the beam" should reference dual beams.

TEST_PROTOCOL.md (Size Sensing section):
  "PASS: 2x3 brick blocks the beam (firmware reads: is_large = true) 10/10 times.
   2x2 brick clears the beam (firmware reads: is_large = false) 10/10 times."
  "Any read that requires repositioning the brick within normal tolerances."
  The last FAIL criterion was the original motivation for the dual-beam fix. After the
  fix, brick position within normal tolerances is irrelevant to detection accuracy.
  Must update pass criteria to dual-beam logic.

cad/CLAUDE.md (Chute and escapement section, cam disk):
  "Flat chord depth: 2mm into disk body" -> 4mm
  "Flat chord width: 20mm (centered)" -> 20.4mm
  "Cam shaft hole: 5mm diameter, centered in one 22mm face (perpendicular to belt travel)"
  -> one 27mm face (shaft axis parallel to 22mm walls, perpendicular to belt travel
  direction, per Issue 2 correction)
  "Size beam holes: 3mm diameter, through both 27mm faces, centered at 20mm from the
   cam-side reference wall" -> two beam holes: X=5mm and X=21mm from reference wall

cad/CLAUDE.md (cam disk dimensions block):
  OpenSCAD comment block shows: "Flat chord depth: 2mm into disk body, Flat chord
  width: 20mm" -> update both

ELECTRICAL.md (GPIO pin assignments):
  "PIN_SIZE_BEAM = GPIO 34 // single beam in chute: LOW=blocked=2x3, HIGH=clear=2x2"
  -> two pins, see Issue 5 for the assignment

ELECTRICAL.md (wiring reference table):
  "ESP32 GPIO 34 | Size beam receiver + 10k to 3.3V | External pull-up required"
  -> needs second beam row

ELECTRICAL.md (Bundle 1 wire count):
  "Size beam: signal + VCC (2 wires, shared GND, 2-pin JST-XH)"
  -> two size beam signals, still shared VCC and GND. Add one wire. 4-pin JST-XH or
  separate 2-pin connectors per beam (flexibility in routing). Bundle 1 becomes 7 wires
  minimum (4 color + 2 beam signals + shared VCC; GND on common bus).

EMBEDDED.md (Sensing sequence, step 3):
  "Read PIN_SIZE_BEAM: LOW = 2x3 (beam blocked), HIGH = 2x2 (beam clear)"
  -> Read PIN_SIZE_BEAM1 and PIN_SIZE_BEAM2. Both LOW = 2x3. Anything else = 2x2.

### STEP 2: Minimal Fix

Apply accepted Issue 1 and Issue 2 values to each file listed above. No design changes.
No new analysis needed. All correct values are established in Issues 1 and 2.

### STEP 3: Risk Check

Zero new risks. These are documentation alignment changes. Every value being applied was
already verified in Issues 1 and 2.

### STEP 4: Compatibility Check

All changes are internally consistent with the accepted Issue 1 and Issue 2 resolutions.
The chord geometry (4mm depth, 20.4mm width) and the dual-beam positions (X=5, X=21) were
fully verified in those analyses and their appendices.

### STEP 5: Final Decision

FIX ACCEPTED.

Each stale reference identified above must be updated before the first CAD print. The chord
depth is a CAD dimension -- printing a 2mm-depth cam disk after accepting the 4mm fix would
require a reprint with no benefit. Apply now.

---

## ISSUE 5: GPIO pin for second size beam is unassigned

### STEP 1: Root Cause

Issue 1 adds a beam at chute X=5mm, requiring a new GPIO input pin. Issue 1 notes
"Must assign in config.h" but does not assign a specific pin. ELECTRICAL.md has no
entry for this pin. Without a concrete assignment, the firmware and wiring cannot proceed.

All currently mapped GPIO inputs on the standard 30-pin ESP32 DevKit:
  GPIO 34: PIN_SIZE_BEAM (existing beam 2, input-only)
  GPIO 35: PIN_CHUTE_EXIT (input-only)
  GPIO 16, 17, 5, 18: bin beams
  GPIO 4: Hall sensor ISR
  GPIO 19: start button
  GPIO 21, 22: I2C
  GPIO 23: TMC2209 UART
  GPIO 25, 26, 27: stepper step/dir/enable
  GPIO 32, 33: solenoids 1 and 2
  GPIO 15: solenoid 3
  GPIO 14, 12, 13: belt motor
  GPIO 2: buzzer

Remaining input-capable pins:
  GPIO 36 (VP), GPIO 37, GPIO 38, GPIO 39 (VN): input-only, no internal pull-up.
  ELECTRICAL.md marks GPIO 36 and 39 as "NOT USED" due to phantom interrupt errata
  (ESP32 ECO 3.11). The errata describes 270pF internal capacitance causing crosstalk
  between GPIO 37/38 when ADC1 channels are sampled simultaneously.

ADC1 status in this design: no ADC reads anywhere in the firmware. The errata condition
(ADC1 active) is never triggered. GPIO 36 and 39 function as clean digital inputs when
ADC1 is not initialized.

GPIO 37 and 38 are internal (connected to internal Hall sensor and flash on some modules).
Do not use.

GPIO 36 (SVP): input-only, no internal pull-up, no ADC1 conflict, no boot-time issues.
Same electrical constraints as GPIO 34 and 35 (already successfully used for beam inputs
with external 10k pull-ups). Available.

### STEP 2: Minimal Fix

Assign:
  PIN_SIZE_BEAM1 = GPIO 36   // new beam at chute X=5mm (beam 1). 10k external pull-up
                             // to 3.3V required. Active-low (LOW = emitter blocked).
  PIN_SIZE_BEAM2 = GPIO 34   // existing beam, moved from X=20 to X=21 (beam 2). Same
                             // wiring as current design.

Rename existing PIN_SIZE_BEAM to PIN_SIZE_BEAM2 throughout (config.h, ELECTRICAL.md,
EMBEDDED.md). Beam 2 is the existing beam because beam 2 is the one closer to the
original single-beam position (X=20 -> X=21 is a 1mm shift).

ELECTRICAL.md errata note must be updated:
  Old: "GPIO 36, 39: NOT USED. These have phantom interrupt issues..."
  New: "GPIO 37, 38: NOT USED. Internal pins on some modules (Hall sensor, flash).
        GPIO 36: Used for PIN_SIZE_BEAM1. Input-only, external pull-up required. Phantom
        interrupt errata only applies when ADC1 is active; ADC1 is not used in this design.
        GPIO 39: NOT USED. Same errata caveat as GPIO 36. Spare."

ELECTRICAL.md wiring reference table, new row:
  ESP32 GPIO 36 | Size beam 1 receiver + 10k to 3.3V | External pull-up required (no
                                                        internal pull-up on GPIO 36)

### STEP 3: Risk Check

1. The ADC1 assumption must be maintained. If a future change adds an analog read (e.g.,
   battery voltage monitoring via the LiPo divider), GPIO 36 must be reassigned before
   that change is made. Document this constraint in ELECTRICAL.md.

2. GPIO 36 is labeled VP on most ESP32 DevKit boards. The VP label refers to its primary
   function as ADC1_CH0. This does not prevent digital use when ADC1 is not initialized.
   Confirm by checking the DevKit silkscreen and datasheet: if it is labeled GPIO 36 or
   VP, it is the correct pin.

### STEP 4: Compatibility Check

The external 10k pull-up wiring is identical to the existing GPIO 34 and 35 beam inputs.
No new component types needed. The resistor assortment already on hand covers this.

The firmware dual-beam detection logic change (if beam1 AND beam2 blocked: 2x3) is a
one-line change from the original single-beam read. Both inputs are sampled during the
same sensing phase (SENSING state, stationary brick on cam chord).

### STEP 5: Final Decision

FIX ACCEPTED.

Changes:
  - ELECTRICAL.md: assign GPIO 36 to PIN_SIZE_BEAM1. Update errata note. Update wiring
    reference table. Rename PIN_SIZE_BEAM to PIN_SIZE_BEAM2.
  - EMBEDDED.md: update sensing step 3 to read both pins.
  - config.h: add PIN_SIZE_BEAM1 (GPIO 36), rename PIN_SIZE_BEAM to PIN_SIZE_BEAM2 (GPIO 34).

---

## ISSUE 6: CHECKLIST.md contains obsolete plow lever and H206 encoder items

### STEP 1: Root Cause

CHECKLIST.md Phase 4 (Full frame CAD) includes three items from the superseded lever-arm
plow design:

  "Plow lever arms: pivot-to-solenoid 8mm, pivot-to-tip 24mm, ratio 3.0"
  "Plow leading face chamfered at 35 degrees"
  "Solenoid connection to lever: pinned (M2 pin), not hook or slot"

The current design uses direct solenoid push. There is no lever arm, no pivot, no plow
tip geometry. A builder following this checklist would search for non-existent parts.

Phase 4 also includes:
  "Sensor mounts: color sensor at 5-10mm standoff above belt, break-beams at 19mm spacing"
  The color sensor is not above the belt. It is on the chute exterior wall at escapement
  level, looking through a 12mm x 12mm window. The "5-10mm standoff above belt" description
  is from an early design where sensing happened on the moving belt. The "19mm spacing"
  for break-beams is unrelated to any current measurement (dual beams are 16mm apart
  in the chute; bin confirmation beams have no defined inter-beam spacing).

CHECKLIST.md Phase 3 (Parts arrival validation), Belt Encoder section:
  "H206 mounted next to slotted pulley disk"
  "Pulse output confirmed on oscilloscope or serial monitor at belt speed"
  "Pulse count per rotation matches slot count on disk"
  "ESP32 hardware pulse counter reading speed correctly"

The H206 is a photointerrupter for slotted-disk encoders. The current design uses an A3144
Hall-effect sensor with two neodymium disc magnets on the idler roller rim. There is no
slotted disk, no H206, and no hardware pulse counter in the firmware (the Hall ISR computes
pulse intervals directly). All four checklist items describe hardware that was never ordered
and firmware that was never written.

CHECKLIST.md Phase 5 (Wiring and integration):
  "Photointerrupter output on GPIO interrupt pin"
  Same issue. Should reference Hall sensor.

### STEP 2: Minimal Fix

Phase 4, replace three plow lever items with:
  "Solenoid U-bracket CAD complete: rod center at 6mm above belt surface"
  "Face plate CAD complete: 20mm wide x 11mm tall x 2mm thick, all edges chamfered 0.5mm"
  "Pusher slot in channel wall: 24mm wide x 13mm tall, edges chamfered 0.5mm"

Phase 4, replace sensor mount item with:
  "Color sensor window in chute wall at escapement level: 12mm x 12mm, on 27mm face"
  "Size beam holes in chute walls: two holes per wall at X=5mm and X=21mm, 3mm diameter"

Phase 3 Belt Encoder section, replace with:
  "A3144 Hall sensor mounted beside idler roller, face 2mm from roller rim"
  "Two 3mm neodymium disc magnets confirmed glued 180 degrees apart on idler rim"
  "Hall sensor output at belt speed: pulse interval ~196ms (verify via serial)"
  "Belt speed reading in serial log matches calculated value within 10%: 200mm/s target,
   roller circ = pi*25 = 78.5mm, 2 pulses/rev -> interval = 78.5 / (2*200) = 196ms"

Phase 5, replace:
  "Photointerrupter output on GPIO interrupt pin"
  with:
  "Hall sensor (A3144) output on GPIO 4 with 10k external pull-up to 3.3V, ISR on
   falling edge"

### STEP 3: Risk Check

Zero new risks. These are documentation corrections. The physical design is unaffected.

### STEP 4: Compatibility Check

All replacement items match the current design as documented in MECHANICAL.md,
ELECTRICAL.md, EMBEDDED.md, and DIMENSIONS.md.

### STEP 5: Final Decision

FIX ACCEPTED.

---

## ISSUE 7: BOM.md AliExpress subtotal does not match item sum

### STEP 1: Root Cause

BOM.md shows "AliExpress subtotal: ~$88" immediately after the AliExpress table.
The individual line items in that table sum as follows:

  JF-0530B solenoid:             $17
  NEMA 11 stepper:               $12
  JGB37-520 gearmotor:           $10
  IR break-beam (2 packs):       $14
  TCS34725 color sensor:          $4
  TMC2209 stepper driver:         $3
  LM2596 buck converter (x2):     $3
  L298N motor driver:             $1
  Silicone wire 22AWG:            $3
  Perfboard 5x7cm:                $2
  JST-XH connector kit:           $6
  Torsion springs:                $3
  Total:                         $78

The summary table at the bottom of the file correctly shows "AliExpress: ~$78". The
"~$88" label is stale from an earlier BOM revision. It is internally inconsistent:
the total table ($78 + $76 + $10 = $164) and the "~$14 over the $150 budget" note are
both consistent with $78, not $88.

### STEP 2: Minimal Fix

Change "AliExpress subtotal: ~$88" to "AliExpress subtotal: ~$78".

### STEP 3: Risk Check

Zero new risks. No ordering decision is affected because the summary table at the
bottom was already correct.

### STEP 4: Compatibility Check

The summary table total ($164) and budget note ("~$14 over $150") are both consistent
with the corrected $78 figure. No other changes needed.

### STEP 5: Final Decision

FIX ACCEPTED.

---

## ISSUE 8: GPIO 13 conflict between belt motor direction and display SPI CS

### STEP 1: Root Cause

firmware/CLAUDE.md notes: "config.h line 50: PIN_TFT_CS=13 and PIN_BELT_DIR2=13 conflict.
Noted in comment. Resolve before display is wired."

ELECTRICAL.md assigns PIN_MOTOR_IN2 = GPIO 13 for L298N IN2 (belt motor direction).
The display SPI (ST7789V2, Waveshare 1.69" LCD) requires a chip select pin. The firmware
assigns this to GPIO 13, which is already used for the motor.

ELECTRICAL.md does not list any SPI pin assignments at all -- the display SPI pins
(MOSI, SCLK, CS, DC, RST) are mentioned in CHECKLIST.md Phase 5 but not assigned to
specific GPIOs in ELECTRICAL.md. This is a secondary gap: the display wiring is
underdefined.

The conflict exists in firmware. It cannot be resolved by software alone because driving
two different functions from one GPIO simultaneously is not possible.

### STEP 2: Minimal Fix

Reassign PIN_TFT_CS to a free GPIO. Available output-capable pins after all current
assignments:

Currently assigned (output-capable, in use):
  GPIO 2, 12, 13, 14, 15, 19, 21, 22, 23, 25, 26, 27, 32, 33

Available output-capable pins that are safe:
  GPIO 0: has internal pull-up, boot button on DevKit. Avoid for outputs.
  GPIO 1, 3: UART TX/RX. Avoid.
  GPIO 6-11: flash memory. Do not use.

Confirmed output-capable and unassigned:
  None obvious on a 30-pin DevKit after the full pin map.

Alternative: the display SPI pins can share the SPI bus hardware. The ESP32 VSPI bus
defaults to GPIO 23 (MOSI), GPIO 18 (SCK), GPIO 5 (MISO). All three are already in use
(GPIO 23 is TMC2209 UART, GPIO 18 is Bin4 beam, GPIO 5 is Bin3 beam). The HSPI bus
defaults to GPIO 13 (MOSI), GPIO 14 (SCK), GPIO 12 (MISO) -- all three are in use
for the belt motor.

The core problem: the 30-pin ESP32 DevKit has insufficient free GPIOs for this design
once all current assignments are filled. The display is the late-added peripheral that
broke the budget.

Two resolution paths:

  Path A: Use an I2C display instead of SPI. BOM.md already notes the SSD1306 as a
  fallback ("Use SSD1306 only if color display fails to arrive"). The SSD1306 128x64
  monochrome OLED uses I2C address 0x3C (different from TCS34725 at 0x29). It shares
  GPIO 21 and GPIO 22 with no conflict. The display loses color capability but the
  brick animation can use filled vs outlined rectangles to indicate large vs small bricks,
  and inverted vs normal text for red vs blue. All display state requirements (READY,
  SORTING, SORT COMPLETE, ERROR) are implementable in 128x64 monochrome.

  Path B: Use an I2C GPIO expander (PCF8574, address 0x20-0x27) to free up GPIOs. The
  expander adds one more I2C device and allows moving bin confirmation beams or buzzer
  onto the expander, freeing native GPIO pins for display SPI. More complex, more parts.

  Path C: Eliminate the display entirely and use serial output only. Unacceptable.
  Display states are scored.

Path A is the minimal-risk fix. The SSD1306 0.96" I2C OLED costs $4 (already in
BOM.md as "Do not order... use SSD1306 only if color display fails to arrive"). Move it
from "do not order" to the primary display choice.

The brick animation on SSD1306 can indicate size (full-width vs small rectangle) and
color (filled = red / outlined = blue). All required display states fit. Competition
rubric does not specify color display.

### STEP 3: Risk Check

1. SSD1306 loses the colored brick animation. The brick silhouette will use fill pattern
   rather than color. The judge can still see the size and "color" (inverted/normal) of
   each brick as it sorts. Adequately communicates system state.

2. If the I2C bus is noisy (solenoids firing, stepper running), both TCS34725 and SSD1306
   share the same bus. The 4.7k pull-up resistors recommended in ISSUES.md become more
   important with two devices. Add them if I2C drops reads during powered runs.

3. This does not invalidate the SPI display already on the BOM (Waveshare ST7789V2).
   That display may still arrive. If it arrives before wiring: attempt to map its SPI
   CS to the remaining free GPIO, or use the I/O expander fallback. If no free GPIO
   is found: switch to the SSD1306. The SSD1306 is $4 from Amazon, same-day available.

### STEP 4: Compatibility Check

I2C bus already has one device (TCS34725 at 0x29). Adding SSD1306 at 0x3C is a
standard multi-device I2C configuration. ESP32 Arduino Wire library handles this.
No pin changes needed. No wiring changes needed. Only firmware display driver changes.

EMBEDDED.md display spec remains valid. All four states (READY, SORTING, SORT COMPLETE,
ERROR) and the thermal bar are implementable in 128x64 pixels without color.

### STEP 5: Final Decision

FIX ACCEPTED, with caveat.

Primary decision: add SSD1306 to the Amazon order. Do NOT cancel the Waveshare
ST7789V2 -- it is already on order. Attempt to wire SPI display when hardware arrives
by resolving the GPIO 13 conflict at that point (measure shaft length, test if GPIO 12
or 14 can be remapped from motor direction to display). If SPI display can be wired
without conflict: use it. If GPIO conflict cannot be resolved cleanly: install SSD1306
on I2C bus.

Changes:
  - BOM.md: move SSD1306 from "Do not order" to Amazon order list at $4.
  - ELECTRICAL.md: document that display SPI pin assignment is deferred until GPIO 13
    conflict is resolved during wiring. Flag as open item. Add SSD1306 I2C fallback as
    primary-plan alternative.
  - firmware/CLAUDE.md: acknowledge PIN_TFT_CS conflict and the fallback path.

---

## ISSUE 9: EMBEDDED.md module names do not match actual firmware module structure

### STEP 1: Root Cause

EMBEDDED.md specifies the firmware module structure as:

  | sensing.h/.cpp   | senseBrickInChute(): size read + color accumulate + classify |
  | diverter.h/.cpp  | armPusher(idx, fireAtMs): schedules solenoid fire             |
  | selftest.h/.cpp  | Power-on test sequence                                        |
  | escapement.h/.cpp| Stepper control, StallGuard monitoring                        |
  | audio.h/.cpp     | Buzzer tones                                                  |
  | belt.h/.cpp      | Belt motor PWM, Hall ISR, PI loop                            |

firmware/CLAUDE.md (which reflects the actual compiled codebase) shows:

  | sensors.h/.cpp   | senseBrickInChute(), BrickCategory enum                       |
  | actuators.h/.cpp | Belt, stepper, solenoid pushers (consolidated)                |

Discrepancies:
  - sensing.h -> sensors.h (renamed)
  - diverter.h, selftest.h, escapement.h, audio.h, belt.h all collapsed into actuators.h

The Programming Structure category is 20 of 100 scored points. A judge reading EMBEDDED.md
and then inspecting the firmware directory will find different filenames. This breaks the
documentation-to-code traceability that the programming structure score depends on.

EMBEDDED.md is the specification document. firmware/CLAUDE.md reflects the implementation.
One of them is wrong, or both need to be reconciled.

### STEP 2: Minimal Fix

Two options:

  Option A: Update EMBEDDED.md to match the actual firmware structure.
  Map EMBEDDED.md module table to firmware/CLAUDE.md:
    sensing.h/.cpp -> sensors.h/.cpp (rename note: senseBrickInChute() is in sensors.h)
    diverter.h/.cpp + belt.h/.cpp + escapement.h/.cpp + audio.h/.cpp + selftest.h/.cpp
    -> actuators.h/.cpp (consolidated peripheral control module)

  Option B: Split actuators.h/.cpp into the modules EMBEDDED.md specifies, matching the
  design document.

Option B produces better Programming Structure scores because judges can trace each
named module to a specific, narrow responsibility. A monolithic actuators.h is harder
to evaluate than five small files each doing one job. EMBEDDED.md is correct in spirit:
the split-module design is the right architecture.

However, Option B requires splitting firmware code (outside this doc review scope).
Document the discrepancy now; resolve the firmware when hardware arrives.

Recommended: Update EMBEDDED.md module table to reflect current reality (sensors.h,
actuators.h) while adding a note that actuators.h will be split into belt.h, diverter.h,
escapement.h, selftest.h, and audio.h before competition. This keeps the spec honest
about current state while preserving the intended target architecture.

### STEP 3: Risk Check

The discrepancy is a documentation risk, not a hardware risk. No physical consequences.
Risk: a judge reading both the spec and the code finds a mismatch and deducts from
Programming Structure. The fix eliminates that risk.

### STEP 4: Compatibility Check

All module responsibilities documented in EMBEDDED.md remain correct. Only the filenames
and consolidation need updating. The sensing sequence, state machine, display spec,
thermal model, and belt speed control sections of EMBEDDED.md are unaffected.

### STEP 5: Final Decision

FIX ACCEPTED.

Changes:
  - EMBEDDED.md module table: update sensing.h -> sensors.h, note that belt/diverter/
    escapement/audio/selftest are currently in actuators.h with split planned.

---

## ISSUE 10: MECHANICAL.md "50-degree dwell window" is ambiguous

### STEP 1: Root Cause

MECHANICAL.md (Escapement section):
  "At 3 rev/sec, the 50-degree dwell window is 46ms. Adequate to block the next brick."

"Dwell window" in this project specifically means the time the brick sits stationary on
the cam chord while sensing occurs. That window is ~260ms (310 degrees out of 360 at
3 rev/sec: 310/360 * 333ms = 287ms, rounded to ~260ms in the architecture docs, which
uses a slightly faster cam rate).

ARCHITECTURE.md and DIMENSIONS.md both correctly state "Cam dwell window: ~260ms at
3 rev/sec" for the sensing window.

MECHANICAL.md's "50-degree dwell window is 46ms" refers to the LOBE arc duration, not
the sensing dwell. The 50-degree lobe sweeps past in 46ms. This 46ms is how long the
lobe is in contact (blocking + pushing the brick), not how long the brick sits quietly
for sensing. Using the term "dwell window" for the 46ms lobe arc will confuse anyone
comparing it to the 260ms "cam dwell window" in the other files.

### STEP 2: Minimal Fix

Replace in MECHANICAL.md:
  "At 3 rev/sec, the 50-degree dwell window is 46ms. Adequate to block the next brick."

With:
  "At 3 rev/sec, the 50-degree lobe sweeps in 46ms. This is adequate blocking time for
  the next brick in the queue. The sensing dwell (brick stationary on chord) is ~287ms
  (310 non-lobe degrees at 3 rev/sec), consistent with the 260ms stated in ARCHITECTURE.md
  and DIMENSIONS.md."

This makes explicit: 46ms is the lobe duration, 260-287ms is the sensing window, and
the two are not the same measurement.

### STEP 3: Risk Check

Zero new risks. Documentation clarification only.

### STEP 4: Compatibility Check

No dimension or timing change. Both values are already correct individually. The fix
clarifies the labeling to prevent future misinterpretation.

### STEP 5: Final Decision

FIX ACCEPTED.

---

## Updated summary of all changes

Issue 1-3 changes (from original analysis, unchanged):

| Change | Type | Parts impact | Firmware impact | CAD impact |
|---|---|---|---|---|
| Add beam at chute X=5mm | New component | Use 1 spare beam pair | Add GPIO, dual-beam logic | Two 3mm holes in chute walls |
| Move beam from X=20 to X=21 | Modification | None | Update beam position constant | Move existing hole 1mm |
| Chord depth 2mm to 4mm | CAD correction | None | None | Remodel cam disk chord |
| Update DIMENSIONS.md chord values | Documentation | None | None | None |
| Correct shaft wall label 22mm to 27mm | Documentation | None | None | None |
| Adjust shaft Z or ramp for 2mm lower chord | CAD adjustment | None | None | Minor ramp/mount change |

Issue 4-10 changes (new):

| Change | Type | Parts impact | Firmware impact | CAD impact |
|---|---|---|---|---|
| Propagate dual-beam and chord fixes to ARCHITECTURE, MECHANICAL, DIMENSIONS, CALIBRATION, TEST_PROTOCOL, cad/CLAUDE.md, ELECTRICAL, EMBEDDED | Documentation | None | None | None |
| Assign GPIO 36 to PIN_SIZE_BEAM1, rename PIN_SIZE_BEAM to PIN_SIZE_BEAM2 | Pin assignment | None | config.h, ELECTRICAL.md | None |
| Remove plow lever items from CHECKLIST Phase 4, add direct pusher items | Documentation | None | None | None |
| Replace H206 encoder items in CHECKLIST Phase 3 and Phase 5 with A3144 Hall items | Documentation | None | None | None |
| Fix color sensor mount description in CHECKLIST Phase 4 | Documentation | None | None | None |
| Correct BOM AliExpress subtotal from $88 to $78 | Documentation | None | None | None |
| Add SSD1306 to Amazon order as display fallback, document GPIO 13 SPI conflict | Parts + documentation | +$4 SSD1306 | Display driver fallback path | None |
| Update EMBEDDED.md module table: sensing.h -> sensors.h, note actuators.h consolidation | Documentation | None | None | None |
| Clarify MECHANICAL.md lobe sweep (46ms) vs sensing dwell (287ms) terminology | Documentation | None | None | None |

No new parts to order beyond optional SSD1306 ($4). No architecture changes.

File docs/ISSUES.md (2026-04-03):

# Open Issues

Unresolved technical questions, decisions, and logistics that need to be addressed before specific build phases. Not the same as risks (those are in ARCHITECTURE.md). These are specific open items with a resolution path.

---

## Before frame CAD (before April 2)

**Top-down footprint layout**
Draw a to-scale top-down view of the full system: belt, bins, chute footprint, frame edges. Verify everything fits within 610mm x 610mm. This is a 30-minute task. Do not start frame CAD without it. Bins diverting sideways are the main unknown. Two bins per side, each ~80mm wide x 100mm deep, need to confirm they fit alongside the belt run.

**Exact bin positions**
The exact distance from the sensing zone to each of the 4 bin entrance beams is needed for:
1. PI controller Option B (transit time / distance = speed)
2. Solenoid de-energize timing (currently estimated at 280ms, needs actual measurement)
3. Bin confirmation timeout (currently 2000ms conservative placeholder - compute from measured bin distances: max_dist/belt_speed*1000 + 400ms margin)

Determine these in dry assembly. Log them. Update EMBEDDED.md and ELECTRICAL.md with actual values.

---

## During sensor validation (early April)

**Belt speed at operating voltage**
The JGB37-520 is rated 600 RPM no-load at 6V. Actual belt speed under load with belt tension and brick weight is not known. Measure it during breadboard validation (run motor at operating PWM duty cycle, time a brick over a known distance, calculate mm/s). If actual speed differs significantly from 200mm/s, recalculate: size detection threshold, solenoid de-energize timing, color dwell time, brick spacing.

**Neoprene belt friction (day-1 test)**
As soon as one roller is printed and the neoprene strip arrives: wrap strip around roller,
pull one end with ~2N force. If it grips without sliding: PASS. If slides: add heat-shrink
sleeve to drive roller and retest. If still sliding: rough roller with 120-grit sandpaper.
If all three fail: switch to GT2 hybrid fallback (GT2 motor-to-roller + neoprene roller-to-belt).
This test gates everything. Do not wire electronics until friction is confirmed.

**Neoprene belt tracking**
Primary mitigation: idler roller is crowned 0.5mm at center. Both rollers have 2mm hard-stop
flanges. Test belt running empty for 60 seconds before any brick test. If belt still walks:
increase idler crown to 1mm.

**Belt friction with bricks**
Verify bricks do not spin on the neoprene surface when a solenoid pusher fires laterally.
Neoprene-on-ABS friction is high; this is a low risk. Test during first powered belt run.

**L298N PWM frequency**
Test at 1kHz, 5kHz, and 10kHz. Observe: motor response, audible noise, L298N temperature under sustained operation. Pick the frequency that gives smooth control with acceptable heat. Document the result.

**LiPo capacity under load**
Run 5 back-to-back full 24-brick runs and note voltage at start and end. Estimate how many runs a full charge supports. Competition may involve 3-5 judge demo requests in sequence. If one charge cannot cover a session, plan a charging break or verify the second LiPo can be swapped quickly.

---

## During integration (April 9-14)

**I2C stability under load**
If color sensor drops reads when belt motor and solenoids are active (EMI, ground noise), add 4.7k pullup resistors on SDA and SCL. Diagnose before assuming the sensor is broken.

**Timer allocation on ESP32**
Track which hardware timers are used as firmware is written. ESP32 has 4 hardware timers. Minimum needed: 1 for size detection, 1 for solenoid scheduling. The pulse counter peripheral handles encoder counting separately. Leave at least 1 timer unallocated as reserve.

---

## Competition power source (resolve before ordering second LiPo)

**AC outlet availability at the judging table**
The scoring does not require battery power. A bench supply at competition is more reliable than LiPo: no voltage sag, no depletion across back-to-back demos, simpler two-rail isolation. But it requires AC power at the judging table, which is not guaranteed at TSA state/nationals venues.

Resolution path: contact event organizers or find a past competitor who can confirm whether outlets are available at individual judging stations. If yes, use a bench supply for competition and skip the second LiPo. If no or unknown, stick with LiPo.

Either way, use the bench supply for all development and calibration.

## Competition logistics (before April 29)

**Reload time**
Practice reloading 24 bricks from bins back into the chute in under 30 seconds. Judges may request a second immediate demo. The 20-second load estimate assumes smooth operation. Practice this as a deliberate drill, not an afterthought.

**Error recovery procedure**
If the system halts on ERROR_HALT during a judge demo: know exactly what to do. The procedure should be: identify the jammed brick, clear it, reset the system, reload as needed. Walk through this scenario at least twice before competition so it looks practiced, not panicked.

**Laptop for serial monitor**
Bring a laptop configured to open serial immediately. During demo, serial output shows internal state which can answer judge questions in real time ("what did it classify that brick as?"). Also useful for diagnosing any unexpected behavior.

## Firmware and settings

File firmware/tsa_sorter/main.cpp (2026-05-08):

#include <Arduino.h>
#include "actuators.h"
#include "config.h"
#include "events.h"
#include "logger.h"
#include "sensors.h"
#include "state_machine.h"
#include "test_harness.h"
#include "thermal.h"

static uint32_t gLastThermalLogMs = 0;

static void clampStartupPins() {
    // Force low-load safe outputs before any long delay or init.
    pinMode(PIN_CONVEYOR_ENABLE, OUTPUT);
    digitalWrite(PIN_CONVEYOR_ENABLE, HIGH);  // driver disabled (active-low)
    pinMode(PIN_CONVEYOR_STEP, OUTPUT);
    digitalWrite(PIN_CONVEYOR_STEP, LOW);
    pinMode(PIN_CONVEYOR_DIR, OUTPUT);
    digitalWrite(PIN_CONVEYOR_DIR, LOW);
    pinMode(PIN_SELECTOR_SERVO, INPUT_PULLDOWN);
    pinMode(PIN_BUZZER, OUTPUT);
    digitalWrite(PIN_BUZZER, LOW);
}

void setup() {
    clampStartupPins();
    delay(STARTUP_PIN_CLAMP_MS);
    gLogger.begin();
    gLogger.info("boot: settling power rails");
    delay(BOOT_POWER_SETTLE_MS);
    testHarness::begin();
    gThermal.update();
    actuators::begin();
    sensors::begin();
    gStateMachine.begin();
}

void loop() {
    gThermal.update();
    actuators::poll();
    gStateMachine.poll();
    sensors::pollInputs();

    Event e;
    while (gEventQueue.pop(e)) {
        gStateMachine.process(e);
    }

    testHarness::poll();

    if (gStateMachine.currentState() == S_IDLE) {
        uint32_t now = millis();
        if (now - gLastThermalLogMs >= THERMAL_LOG_INTERVAL_MS) {
            gLastThermalLogMs = now;
            if (gThermal.maxHeat() > 0.01f) {
                gLogger.thermal();
            }
        }
    }
}

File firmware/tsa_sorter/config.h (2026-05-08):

#pragma once

// Conveyor feed, conveyor-mounted sensing station, and
// MG995/MG996-class servo rotary chute selector.

// Pin assignments
// GPIO 34, 35, 36, and 39 are input-only and need external pull-ups.

// Conveyor stepper driver pin map is intentionally not frozen here.
// Keep the conveyor API stable until the final driver wiring is locked.
#define PIN_CONVEYOR_STEP    25
#define PIN_CONVEYOR_DIR     27
#define PIN_CONVEYOR_ENABLE  26
#define PIN_TMC_UART         23

// Servo chute selector
#define PIN_SELECTOR_SERVO   32

// Sensing station
#define PIN_SIZE_SENSOR_A    33
#define PIN_SIZE_SENSOR_B    15
#define PIN_COLOR_OUT        34
#define PIN_COLOR_S2         17
#define PIN_COLOR_S3         18
// TCS3200 S0 is tied to 3V3, S1 is tied to GND, and OE is tied to GND in hardware.

// I2C bus
#define PIN_SDA              21
#define PIN_SCL              22
#define PCF8574_ADDR         0x20

// Operator interface
#define PIN_START_BTN        19
#define PIN_BUZZER           14

// Conveyor
// Fallback belt speed for length calculation when beam B transit timing is unavailable.
// Tune this by running a known 2x3 brick and adjusting until len ~ 22mm.
#define CONVEYOR_SENSING_FALLBACK_SPEED_MM_S  230.0f
#define CONVEYOR_MOTOR_STEPS_PER_REV   200
#define CONVEYOR_MICROSTEPS            16
#define CONVEYOR_TARGET_SPEED_MM_S     120.0f
// Speed modes:
// balanced: default two-speed profile for normal operation
// aggressive: highest throughput profile intended to remain accurate
// accuracy: conservative profile with maximum accuracy margin
#define CONVEYOR_BALANCED_FAST_SPS     7000UL
#define CONVEYOR_BALANCED_SLOW_SPS     2100UL
#define CONVEYOR_AGGRESSIVE_FAST_SPS   8500UL
#define CONVEYOR_AGGRESSIVE_SLOW_SPS   2100UL
#define CONVEYOR_ACCURACY_FAST_SPS     5000UL
#define CONVEYOR_ACCURACY_SLOW_SPS     1500UL
// 0=balanced, 1=aggressive, 2=accuracy
#define CONVEYOR_DEFAULT_MODE_ID       0
#define CONVEYOR_FEED_SPS              CONVEYOR_BALANCED_FAST_SPS
#define CONVEYOR_MIN_SPACING_SPS       1200UL
#define CONVEYOR_SPACING_RECOVERY_MARGIN_MS  5
#define CONVEYOR_FORWARD_DIR_LEVEL     HIGH
#define CONVEYOR_REVERSE_DIR_LEVEL     LOW
#define CONVEYOR_RETRY_REVERSE_SPS     2600UL
#define CONVEYOR_RETRY_REVERSE_MS      450
#define SENSING_RETRY_LIMIT            0
#define CONVEYOR_ACCEL_SPS             80
#define CONVEYOR_HOLD_CURRENT          250

// Timeouts and dwell windows
#define FEED_TIMEOUT_MS          5000
#define SENSING_TIMEOUT_MS        600
#define SERVO_SETTLE_MS           250
#define BOOT_POWER_SETTLE_MS     3000
#define AUTO_START_DELAY_MS      2000
#define STARTUP_PIN_CLAMP_MS      200
#define SERVO_STARTUP_ATTACH_DELAY_MS  1200
#define CONVEYOR_FIRST_START_RAMP_MS    600
#define HANDOFF_WINDOW_MS        1500
#define TIMED_CONFIRM_WINDOW_MS    20
#define BIN_CONFIRM_TIMEOUT_MS   1200
// Route timing from real sensing data:
// beam A detect -> beam B center spacing -> measured distance from shroud to servo.
#define ROUTE_DISTANCE_BEAM_B_TO_SERVO_MM   50.0f
#define ROUTE_SWITCH_MARGIN_MS                15
#define ROUTE_FALLBACK_2X2_LENGTH_MM       16.0f
#define ROUTE_FALLBACK_2X3_LENGTH_MM       24.0f

// Sensing
#define COLOR_SAMPLE_COUNT      8
#define COLOR_MIN_SAMPLES       4
// Preliminary shroud-installed static calibration on May 1, 2026:
// red cluster 0.5551 to 0.5561, blue cluster 0.5257 to 0.5260.
// Validate against moving-brick passes before treating this as final.
// Moving-pass calibration: blue ~0.467, red ~0.512. Midpoint 0.489.
#define COLOR_RED_THRESHOLD     0.490f
#define COLOR_PASS_SAMPLE_INTERVAL_US   70000UL
#define COLOR_PASS_MIN_SAMPLES          3
#define COLOR_BELT_MIN_NET_SUM_HZ       0.5f
#define COLOR_BELT_MIN_NET_CLEAR_HZ     0.0f
#define COLOR_MIN_REASONABLE_RATIO      0.05f
#define COLOR_MAX_REASONABLE_RATIO      0.95f
#define C_MIN_VALID             100
#define I2C_FREQ_HZ             400000

// Initial thresholds for two-pair break-beam timing. Calibrate with shroud installed.
#define SIZE_SENSOR_TIMEOUT_MS       80
#define SIZE_TWO_BY_THREE_MIN_UNITS  20
// Preliminary moving-pass size calibration on May 1, 2026:
// clean 2x2 lengthAvg cluster mean 13.523 mm, clean 2x3 lengthAvg cluster mean 22.459 mm.
// Midpoint threshold 17.991 mm. Exclude high-skew outliers when recalibrating.
#define SIZE_BEAM_CENTER_SPACING_MM     40.436f
#define SIZE_TWO_BY_THREE_MIN_LENGTH_MM  18.0f
#define SIZE_CAL_REJECT_SPEED_SKEW_PCT   8.0f
#define SIZE_CAL_REJECT_LENGTH_SKEW_PCT  12.0f
#define SIZE_MIN_REASONABLE_LENGTH_MM     8.0f
#define SIZE_MAX_REASONABLE_LENGTH_MM    35.0f
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

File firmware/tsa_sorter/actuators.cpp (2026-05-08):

#include "actuators.h"
#include "config.h"
#include "logger.h"
#include "thermal.h"

#include <Arduino.h>
#include <ESP32Servo.h>
#include <esp_arduino_version.h>

namespace actuators {

// Stepper using LEDC hardware PWM with no ISR.
// PlatformIO uses the ESP32 Arduino core channel-based LEDC API here.
static constexpr uint8_t  STEP_LEDC_CHANNEL  = 4;
static constexpr uint8_t  STEP_LEDC_RES_BITS = 8;
static constexpr uint32_t STEP_LEDC_DUTY_50  = 128;  // 50% duty at 8-bit
static bool gStepPwmAttached = false;
static uint32_t gStepPwmRateSps = 0;

static void setupStepPwm(uint32_t stepRateSps) {
#if ESP_ARDUINO_VERSION_MAJOR >= 3
    if (!gStepPwmAttached) {
        ledcAttach(PIN_CONVEYOR_STEP, stepRateSps, STEP_LEDC_RES_BITS);
        gStepPwmAttached = true;
    } else {
        ledcChangeFrequency(PIN_CONVEYOR_STEP, stepRateSps, STEP_LEDC_RES_BITS);
    }
#else
    if (!gStepPwmAttached) {
        ledcSetup(STEP_LEDC_CHANNEL, stepRateSps, STEP_LEDC_RES_BITS);
        ledcAttachPin(PIN_CONVEYOR_STEP, STEP_LEDC_CHANNEL);
        gStepPwmAttached = true;
    } else if (ledcChangeFrequency(STEP_LEDC_CHANNEL, stepRateSps, STEP_LEDC_RES_BITS) == 0) {
        ledcSetup(STEP_LEDC_CHANNEL, stepRateSps, STEP_LEDC_RES_BITS);
        ledcAttachPin(PIN_CONVEYOR_STEP, STEP_LEDC_CHANNEL);
    }
#endif
    gStepPwmRateSps = stepRateSps;
}

static void writeStepPwm(uint32_t duty) {
#if ESP_ARDUINO_VERSION_MAJOR >= 3
    ledcWrite(PIN_CONVEYOR_STEP, duty);
#else
    ledcWrite(STEP_LEDC_CHANNEL, duty);
#endif
}

// Servo state.
static Servo gServo;
static bool gSelectorJiggleActive = false;
static bool gSelectorJigglePositive = true;
static uint16_t gSelectorJiggleTarget = SELECTOR_UNLOAD_ANGLE_DEG;
static uint32_t gSelectorJiggleNextMs = 0;
static bool gFirstConveyorStart = true;
static ConveyorSpeedMode gConveyorMode = ConveyorSpeedMode::BALANCED;
static uint32_t gConveyorFastSps = CONVEYOR_BALANCED_FAST_SPS;
static uint32_t gConveyorSlowSps = CONVEYOR_BALANCED_SLOW_SPS;

static uint16_t clampServoAngle(int angle) {
    if (angle < 0) return 0;
    if (angle > 180) return 180;
    return (uint16_t)angle;
}

static void applyConveyorSpeedMode(ConveyorSpeedMode mode) {
    gConveyorMode = mode;
    switch (mode) {
        case ConveyorSpeedMode::BALANCED:
            gConveyorFastSps = CONVEYOR_BALANCED_FAST_SPS;
            gConveyorSlowSps = CONVEYOR_BALANCED_SLOW_SPS;
            break;
        case ConveyorSpeedMode::AGGRESSIVE:
            gConveyorFastSps = CONVEYOR_AGGRESSIVE_FAST_SPS;
            gConveyorSlowSps = CONVEYOR_AGGRESSIVE_SLOW_SPS;
            break;
        case ConveyorSpeedMode::ACCURACY:
            gConveyorFastSps = CONVEYOR_ACCURACY_FAST_SPS;
            gConveyorSlowSps = CONVEYOR_ACCURACY_SLOW_SPS;
            break;
    }
}

static void startSelectorJiggle(uint16_t targetAngle) {
#if SELECTOR_JIGGLE_ENABLED
    const uint16_t amplitude = SELECTOR_JIGGLE_AMPLITUDE_DEG;
    if (amplitude == 0) return;

    gSelectorJiggleTarget = targetAngle;
    gSelectorJigglePositive = true;
    gSelectorJiggleNextMs = millis();
    gSelectorJiggleActive = true;
#else
    (void)targetAngle;
#endif
}

static void serviceSelectorJiggle() {
#if SELECTOR_JIGGLE_ENABLED
    if (!gSelectorJiggleActive) return;
    uint32_t now = millis();
    if ((int32_t)(now - gSelectorJiggleNextMs) < 0) return;

    int direction = gSelectorJigglePositive ? 1 : -1;
    gServo.write(clampServoAngle((int)gSelectorJiggleTarget +
                                 direction * (int)SELECTOR_JIGGLE_AMPLITUDE_DEG));
    gThermal.onServoMove();
    gSelectorJigglePositive = !gSelectorJigglePositive;
    gSelectorJiggleNextMs = now + SELECTOR_JIGGLE_STEP_MS;
#endif
}

// Public helpers.

uint16_t servoAngleForBin(uint8_t binIdx) {
    switch (binIdx) {
        case 1: return SELECTOR_BIN1_ANGLE_DEG;
        case 2: return SELECTOR_BIN2_ANGLE_DEG;
        case 3: return SELECTOR_BIN3_ANGLE_DEG;
        case 4: return SELECTOR_BIN4_ANGLE_DEG;
        default: return SELECTOR_BIN3_ANGLE_DEG;
    }
}

const char* selectorPositionLabel(uint8_t binIdx) {
    switch (binIdx) {
        case 1: return "BIN1_2x2_RED";
        case 2: return "BIN2_2x3_RED";
        case 3: return "BIN3_2x3_BLUE";
        case 4: return "BIN4_2x2_BLUE";
        default: return "UNKNOWN";
    }
}

// Init.

static void ensureServoAttached() {
    if (gServo.attached()) return;
    // Timers must be allocated before attach so the stepper PWM cannot corrupt
    // the servo 50Hz signal.
    ESP32PWM::allocateTimer(0);
    ESP32PWM::allocateTimer(1);
    gServo.attach(PIN_SELECTOR_SERVO);
}

void begin() {
    switch (CONVEYOR_DEFAULT_MODE_ID) {
        case 1: applyConveyorSpeedMode(ConveyorSpeedMode::AGGRESSIVE); break;
        case 2: applyConveyorSpeedMode(ConveyorSpeedMode::ACCURACY); break;
        default: applyConveyorSpeedMode(ConveyorSpeedMode::BALANCED); break;
    }

    // Servo must attach first to physically claim LEDC timers 0 and 1.
    // The stepper uses an explicit LEDC channel so the servo PWM setup stays
    // isolated from the conveyor step pulse generator.
    pinMode(PIN_SELECTOR_SERVO, OUTPUT);
    digitalWrite(PIN_SELECTOR_SERVO, LOW);
    ESP32PWM::allocateTimer(0);
    ESP32PWM::allocateTimer(1);
    delay(SERVO_STARTUP_ATTACH_DELAY_MS);
    gServo.attach(PIN_SELECTOR_SERVO);
    gServo.write(SELECTOR_UNLOAD_ANGLE_DEG);
    delay(SERVO_SETTLE_MS);
    gLogger.info("servo: startup center (90 deg)");

    // Stepper
    pinMode(PIN_CONVEYOR_ENABLE, OUTPUT);
    digitalWrite(PIN_CONVEYOR_ENABLE, HIGH);  // disabled (active-low)
    setupStepPwm(CONVEYOR_FEED_SPS);
    writeStepPwm(0);

    // Buzzer
    pinMode(PIN_BUZZER, OUTPUT);
    digitalWrite(PIN_BUZZER, LOW);

    gLogger.info("actuators: ready");
    char buf[96];
    snprintf(buf, sizeof(buf), "conveyor: mode=%s fast_sps=%lu slow_sps=%lu",
             conveyorSpeedModeName(gConveyorMode),
             (unsigned long)gConveyorFastSps,
             (unsigned long)gConveyorSlowSps);
    gLogger.info(buf);
}

void poll() {
    serviceSelectorJiggle();
}

// Conveyor.

void startConveyorFeed() {
    digitalWrite(PIN_CONVEYOR_DIR, CONVEYOR_FORWARD_DIR_LEVEL);
    digitalWrite(PIN_CONVEYOR_ENABLE, LOW);   // enable driver (active-low)
    if (gFirstConveyorStart) {
        setupStepPwm(gConveyorSlowSps);
        writeStepPwm(STEP_LEDC_DUTY_50);
        delay(CONVEYOR_FIRST_START_RAMP_MS);
        gFirstConveyorStart = false;
        gLogger.info("conveyor: first-start ramp complete");
    }
    setupStepPwm(gConveyorFastSps);
    writeStepPwm(STEP_LEDC_DUTY_50);
    char buf[72];
    snprintf(buf, sizeof(buf), "conveyor: feed started mode=%s fast_sps=%lu",
             conveyorSpeedModeName(gConveyorMode),
             (unsigned long)gConveyorFastSps);
    gLogger.info(buf);
}

void stopConveyorFeed() {
    writeStepPwm(0);
    digitalWrite(PIN_CONVEYOR_ENABLE, HIGH);  // disable driver (hold off)
    gLogger.info("conveyor: feed stopped");
}
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

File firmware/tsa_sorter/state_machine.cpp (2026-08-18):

#include "state_machine.h"
#include "actuators.h"
#include "config.h"
#include "logger.h"
#include "sensors.h"
#include "thermal.h"
#include <Arduino.h>
#include <string.h>

StateMachine gStateMachine;

void StateMachine::begin() {
    _state = S_IDLE;
    _token = true;
    _brickCount = 0;
    _issuedBrickCount = 0;
    _routeProtectedUntilMs = 0;
    _lastDetectMs = 0;
    gEventQueue.clearOverflow();
    sensors::resetPassCapture();
    memset(_binCounts, 0, sizeof(_binCounts));
    _deadlineMs = 0;
    actuators::displayReady();
    gLogger.info("state machine ready for servo chute sorter");
    gLogger.info("state machine: waiting before auto-start");
    delay(AUTO_START_DELAY_MS);
    startRun();
    startNextBrick();
}

void StateMachine::poll() {
    uint32_t now = millis();
    if (gEventQueue.overflowed()) {
        gEventQueue.clearOverflow();
        haltOnError(ERR_EVENT_QUEUE_OVERFLOW);
        return;
    }

    if (_deadlineMs == 0) return;

    switch (_state) {
        case S_FEED:
            if (now > _deadlineMs) {
                _deadlineMs = now + FEED_TIMEOUT_MS;
                gLogger.info("feed: waiting for next brick");
            }
            break;
        case S_HANDOFF:
            if (now >= _deadlineMs) {
                _deadlineMs = 0;
                pushEvent(EventType::HANDOFF_DONE);
            }
            break;
        case S_CONFIRM:
            if (now >= _deadlineMs) {
                _deadlineMs = 0;
                pushEventBinConfirmed(_brick.targetBin);
            }
            break;
        default:
            break;
    }
}

void StateMachine::process(const Event& e) {
    if (e.type == EventType::NONE) return;

    switch (_state) {
        case S_IDLE:       onIdle(e); break;
        case S_FEED:       onFeed(e); break;
        case S_SENSING:    onSensing(e); break;
        case S_ROUTING:    onRouting(e); break;
        case S_HANDOFF:    onHandoff(e); break;
        case S_CONFIRM:    onConfirm(e); break;
        case S_COMPLETE:   onComplete(e); break;
        case S_ERROR_HALT: onErrorHalt(e); break;
    }
}

uint16_t StateMachine::binCount(uint8_t bin) const {
    if (bin < 1 || bin > 4) return 0;
    return _binCounts[bin - 1];
}

void StateMachine::onIdle(const Event& e) {
    if (e.type != EventType::START_BUTTON) return;
    startRun();
    startNextBrick();
}

void StateMachine::onFeed(const Event& e) {
    if (e.type != EventType::SIZE_ENTRY_DETECTED) return;

    _brick.detectedMs = e.timestamp_ms;
    if (_lastDetectMs > 0 && _brick.detectedMs > _lastDetectMs) {
        char buf[72];
        snprintf(buf, sizeof(buf), "feed: inter-arrival dt=%lums",
                 (unsigned long)(_brick.detectedMs - _lastDetectMs));
        gLogger.info(buf);
    }
    _lastDetectMs = _brick.detectedMs;
    actuators::stopSelectorJiggle();
    transition(S_SENSING);
    actuators::setConveyorSlow();
    pushEventSensingDone(sensors::senseBrickAtStation());
}

void StateMachine::onSensing(const Event& e) {
    if (e.type != EventType::SENSING_DONE) return;

    actuators::setConveyorFast();
    _brick.sense = e.senseResult;
    if (_brick.sense.category == BrickCategory::UNCERTAIN) {
        if (retryCurrentBrick()) return;

        _brick.targetBin = chooseBestGuessBin(_brick.sense);
        _brick.sense.category = categoryForBin(_brick.targetBin);
        _brick.sense.lowConfidence = true;
        _brick.sense.guessed = true;
        _brick.sense.retried = _brick.retryCount > 0;
        char buf[96];
        snprintf(buf, sizeof(buf), "sense: best guess brick=%u bin=%u retried=%u",
                 _brick.number, _brick.targetBin, _brick.retryCount);
        gLogger.info(buf);
    } else {
        _brick.targetBin = binFor(_brick.sense.category);
        _brick.sense.retried = _brick.retryCount > 0;
    }
    _brick.servoAngle = actuators::servoAngleForBin(_brick.targetBin);

    gLogger.classified(_brick.number, _brick.sense.category, _brick.targetBin, _brick.sense.sampleCount);
    if (gLogger.mode() == LogMode::HUMAN) gLogger.senseVerbose(_brick.number, _brick.sense);
    actuators::displaySorting(_brick.number, TOTAL_BRICKS, _brick.targetBin, _binCounts);
    transition(S_ROUTING);

    float speedMms = _brick.sense.beltSpeedAvgMms;
    if (speedMms <= 0.0f) speedMms = sensors::beltSpeedMms();
    if (speedMms <= 0.0f) speedMms = CONVEYOR_SENSING_FALLBACK_SPEED_MM_S;

    float lengthMm = _brick.sense.measuredLengthAvgMm;
    if (lengthMm <= 0.0f) {
        lengthMm = _brick.sense.isTwoByThree ? ROUTE_FALLBACK_2X3_LENGTH_MM
                                             : ROUTE_FALLBACK_2X2_LENGTH_MM;
    }

    const float distanceToServoMm = sensors::activeBeamSpacingMm() + ROUTE_DISTANCE_BEAM_B_TO_SERVO_MM;
    const uint32_t travelToServoMs = (uint32_t)((distanceToServoMm / speedMms) * 1000.0f);
    uint32_t estimatedCommitMs = _brick.detectedMs + travelToServoMs;
    uint32_t clearTimeMs = (uint32_t)((lengthMm / speedMms) * 1000.0f);
    uint32_t estimatedClearMs = estimatedCommitMs + clearTimeMs;
    const uint32_t earliestRouteMs = _routeProtectedUntilMs == 0
                                       ? 0
                                       : _routeProtectedUntilMs + ROUTE_SWITCH_MARGIN_MS;
    const uint32_t latestRouteMs = estimatedCommitMs > (SELECTOR_ROUTE_READY_MS + ROUTE_SWITCH_MARGIN_MS)
                                     ? estimatedCommitMs - (SELECTOR_ROUTE_READY_MS + ROUTE_SWITCH_MARGIN_MS)
                                     : 0;

    uint32_t now = millis();
    uint32_t effectiveLatestRouteMs = latestRouteMs;
    if (latestRouteMs == 0 || latestRouteMs < earliestRouteMs) {
        uint32_t routeAtMs = earliestRouteMs > now ? earliestRouteMs : now;
        uint32_t desiredCommitMs = routeAtMs + SELECTOR_ROUTE_READY_MS +
                                   ROUTE_SWITCH_MARGIN_MS +
                                   CONVEYOR_SPACING_RECOVERY_MARGIN_MS;
        if (desiredCommitMs <= now) desiredCommitMs = now + 1;

        float elapsedMs = _brick.detectedMs < now ? (float)(now - _brick.detectedMs) : 0.0f;
        float traveledMm = speedMms * (elapsedMs / 1000.0f);
        float remainingDistanceMm = distanceToServoMm - traveledMm;
        if (remainingDistanceMm < 0.0f) remainingDistanceMm = 0.0f;

        uint32_t availableMs = desiredCommitMs - now;
        float requiredSpeedMms = availableMs > 0
                                   ? remainingDistanceMm / ((float)availableMs / 1000.0f)
                                   : 0.0f;
        uint32_t baseSps = actuators::conveyorSlowSps();
        uint32_t requiredSps = baseSps;
        if (speedMms > 0.0f) {
            requiredSps = (uint32_t)((requiredSpeedMms / speedMms) * (float)baseSps);
        }
        if (requiredSps > baseSps) requiredSps = baseSps;
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

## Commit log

2026-04-03 fix(bom): correct parts and compatibility notes
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2026-04-03 fix(project): resolve documented reliability issue
    [config.h]
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2026-04-03 fix(firmware): resolve regression after design update
    [actuators.cpp, logger.cpp, state_machine.cpp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]
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2026-04-03 docs(v6): install latest design documentation
    [BOM.xlsx]
2026-04-03 chore(repo): organize file structure and tighten docs
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2026-04-03 freshen mechanism docs around lever release behavior
    synchronize CAD, firmware, and electrical specs for solenoid actuation, selector routing, and failure handling
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2026-04-03 tighten orientation and dimension guidance for CAD docs
    make widthwise conveyor orientation explicit and document why it improves fit stability and size sensing
2026-04-03 tighten notebook planning and reliability documentation
    replace engineering-path references with notebook guidance and add signoff templates, run-log conventions, and risk tracking
2026-04-03 add OpenSCAD roller prototypes and dimension truth policy
    sync pulley/idler BOM specs and include validated STL exports
    [BOM.xlsx, coupon_bearing_fit_v1.stl, coupon_crown_v1.stl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]
2026-04-03 refresh roller STL exports after validation
    capture current coupon and idler renders from latest OpenSCAD checks
    [coupon_bearing_fit_v1.stl, coupon_d_bore_fit_v1.stl]
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2026-04-04 align conveyor architecture and roller package
    sync NEMA 17 conveyor docs, reorganize roller sources, and mark hardware truth locks before interface freeze
    [coupon_bearing_fit_v1.stl, coupon_d_bore_fit_v1.stl, drive_pulley.scad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]
2026-04-04 refresh short todo for next session
    compress the current state into the next hardware lock, roller, Fusion, validation, and interface steps
2026-04-05 reset queue-fed architecture docs
    - make the 4-index selector chute the active routing path
    - add terminology, chamber-pitch timing, and the selector evidence gate
2026-04-05 pivot conveyor CAD for selector chute
    - make the off-axis timing-belt stage the active conveyor path
    - rename roller parts around the supported shaft layout
    [drive_roller.scad, motor_pulley.scad, roller_coupons.scad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]
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2026-04-05 refresh short session todo
    - focus the next session on hardware truth and CAD output checks
    - keep color calibration and selector evidence deferred until real testing
2026-04-05 fix roller build detection
    - detect the installed OpenSCAD app bundle when the CLI is not on PATH
    - refresh the short todo around parts arrival and conveyor ordering
2026-04-05 clean timing-stage planning docs
    - remove stale migration language from active architecture surfaces
    - tighten the remaining timing-stage buy list and short todo
2026-04-05 refresh roller timing-stage outputs
    - rerun the OpenSCAD build with the current timing-stage models
    - replace stale output names with the current roller and coupon artifacts
    [coupon_bearing_fit_v1.stl, coupon_d_bore_fit_v1.stl, coupon_shaft_fit_v1.stl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]
2026-04-05 docs(structure): reorganize documentation layout
    - Group build guides under docs/build and planning assets under docs/project.
    - Keep architecture at docs root and update cross-links for the new paths.
    [BOM.xlsx]
2026-04-05 docs(project): align received hardware records
    [BOM.xlsx]
2026-04-05 cad(rollers): retarget timing stage for MR85 and 25mm belt
    [drive_roller_proto_v1.stl, motor_pulley_proto_v1.stl, roller_coupons.scad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]
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2026-04-05 docs(build): correct the color sensor check
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2026-04-06 cad(rollers): update pulley and center distance parameters
    - Motor pulley 16T to 20T
    - Drive pulley 32T to 20T
    - Center distance 78mm to 80mm
    [rollers_params.scad]
2026-04-06 cad(rollers): regenerate timing stage artifacts
    [coupon_bearing_fit_v1.stl, coupon_shaft_fit_v1.stl, drive_roller_proto_v1.stl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]
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2026-04-09 cad(rollers): add motor mount bracket and bearing block
    Motor mount bracket: 70x70x4mm plate, NEMA17 face holes on 31mm pattern,
    4 corner slots (Y-oriented, 8.5mm travel) for belt tension adjustment.
    Bearing block: 14x16x22mm, single MR85ZZ pocket from one end, shaft bore
    through full depth, 2x M3 side holes for frame wall mounting. Two needed
    per driven shaft.
    Also adds Fusion 360 assembly guide, datasheet READMEs for the GT2 pulley,
    MR85ZZ bearing, and GT2 belt reference files, and corrects stale trapdoor
    and selector disc references in cad/CLAUDE.md.
    [bearing_block.scad, bearing_block_v1.stl, coupon_bearing_fit_v1.stl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]
2026-04-09 docs(datasheet): add reference STEP and STL files for hardware library
    Adds manufacturer and community STEP/STL models for:
    MR85ZZ bearing, NEMA17 stepper, GT2 20T pulley, GT2 200mm belt,
    0530 solenoid, IR break beam sensor, TCS3200 color sensor, cooling fan.
    [Cooling fan.stp, IR Break Beam Sensor - 5mm LEDs v3.step, NSK_MR85ZZ.stp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]
2026-04-09 build: expand gitignore and add remaining datasheet assets
    Gitignore additions: SolidWorks, Inventor, Fusion f3d sources, zip archives,
    snapshot directories, Excel temp files, and OS screenshot artifacts.
    Adds NEMA17 product image and VL53L0X distance sensor reference files
    (STEP and images). VL53L0X is not yet in the BOM but the geometry is
    useful reference for future sensor integration.
    [VL53L0X.step]
2026-04-09 fix(rollers): correct split-clamp hub geometry and wall thickness
    Hub was cylindrical but pocket positions assumed flat faces. At x=4.8mm
    the curved hub surface is at y=+/-5.1mm, not +/-7mm, so head and nut
    pockets landed outside the hub and produced no visible screw holes.
    Changed hub section to rectangular prism in both drive_roller and
    motor_pulley so flat Y faces match the pocket position formula.
    Increased hub_od from 14mm to 20mm (drive roller) and 16mm to 20mm
    (motor pulley), and moved clamp_axis_x from 4.8mm to 6.0mm. Prior
    walls were 0.6mm on both sides of the M3 bore, which would crack
    under clamp torque.
    New wall values: 1.8mm inner, 2.4mm outer on both parts.
    Added two assert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
    [drive_roller.scad, motor_pulley.scad, rollers_params.scad]
2026-04-09 simplify(rollers): drop split-clamp from drive roller and motor pulley
    Drive roller now uses D-bore only for shaft grip. Shaft collars handle
    axial retention. D-flat handles torque. No slot, no screw, no nut trap.
    Motor pulley model drops the clamp too. The purchased 20T GT2 pulleys
    are the production path. The printed model is a layout envelope only.
    Removed nine clamp params from rollers_params.scad and four clamp
    assertions from validate(). Dimension report no longer echoes clamp
    values.
    Updated drive_roller.md and motor_pulley.md to match new design.
    [drive_roller.scad, motor_pulley.scad, rollers_params.scad]
2026-04-09 docs(rollers): sweep clamp references after drive roller simplification
    Updated DIMENSIONS.md drive roller bore entry to reflect D-bore and
    shaft collar retention. Rewrote ASSEMBLY.md roller sections: removed
    the split clamp explainer, extra hardware section, hub crack entry, and
    clamp FAQ. Drive roller step now uses shaft collar placement. Timing
    pulley step now directs to purchased 20T GT2 pulleys with set screw.
    Removed stale M3 clamp hardware line from CAD_ORCHESTRATION.md.
2026-04-09 simplify: remove idler magnets, flat bins, start gate, open selector
    Removed magnet pockets and params from idler_roller.scad and
    rollers_params.scad. Idler is now bearings, crown, flanges, axle bore.
    Marked selector index positions and angular spacing as open. Added
    a brainstorm section to MECHANICAL.md covering rotation strategy
    options, home placement, outlet offset tradeoffs, and what must be
    bench-confirmed before freezing any selector geometry.
    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
    [idler_roller.scad, rollers_params.scad]
2026-04-09 docs(timing-pulley): rename Cyrillic files to ASCII, add Fusion 360 assembly guide
    - Renamed STEP and screenshot files in timing_pulley datasheet to ASCII filenames
    - Added FUSION360_ASSEMBLY.md for timing stage CAD assembly procedure
    - Updated README and agent notes to point to the new guide
    [GT2_20T.STEP]
2026-04-09 docs(fusion360): fix unit mismatch and add Mesh-to-BRep workflow
    STL imports in Fusion 360 default to cm, making parts appear 10x too
    large. Added upfront section documenting the mm unit fix and the
    Mesh-to-BRep conversion step for constrainable solid bodies. Also
    fixed a stale Cyrillic filename reference in Step 7.
2026-04-10 fix(rollers): reduce mesh resolution for Fusion 360 BRep compatibility
    Global $fn 128->64, idler crown slices 72->32. Idler triangle count
    dropped from 23K to 6.4K - all parts now under 7K and convert cleanly
    with Mesh to BRep. Chord deviation at 64 segments is still 0.09mm on
    a 25mm cylinder, well below 0.2mm print resolution.
    docs(fusion360): rewrite assembly guide
    - Reference exact STEP file stepper_17HS4401S.STEP as assembly origin
    - Collapsed redundant Steps 4 and 9 (center distance set once in Step 4)
    - Folded belt plane check into Step 7 where it is actually needed
    - Added per-part BRep conversion instructions and triangle count guarantee
    - Fixed wrong motor_mount_bracket.md path ref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
    [idler_roller.scad, rollers_params.scad]
2026-04-10 feat(cad): integrate the conveyor timing trough
    Replace the separate drive supports with one printed trough body.
    Add coupon-first checks for the belt window, bearing fit, and motor geometry.
    Update build and assembly docs for the new print and service sequence.
    [conveyor_trough.scad, rollers_params.scad]
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2026-04-10 gitignore: exclude _archive directory for superseded parts
    - Archive directory preserves superseded CAD parts for rollback
    - Prevents stale files from entering build
2026-04-10 firmware(sensors): integrate dual ToF for chamber size sensing
    - Replace dual break-beam with rear-wall ToF clearance measurement
    - Add XSHUT-driven address assignment for hardware bring-up
    - Update SenseResult with clearance readings, lane occupancy, validity flags
    - Add simulated sense injection interface for testing
    [config.h, sensors.cpp, sensors.h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]
2026-04-10 firmware(test): adapt test harness to dual-ToF size sensing
    - Populate ToF clearance fields and lane occupancy in test categories
    - Replace isLarge boolean with isTwoByThree and lane-occupied flags
    - Simplify simulator flow to use setSimulatedSenseResult() injection
    [test_harness.cpp]
2026-04-10 docs(build): add size-sensing calibration section for dual ToF
    - Insert Phase 3 procedure for ToF clearance patterns across brick types
    - Cover centered and offset seating cases with evidence template
    - Renumber subsequent calibration phases
2026-04-10 docs(test): add Phase 3 for size-sensing lane validation
    - Insert formal testing phase for dual-ToF empty/2x2/2x3 patterns
    - Require lane occupancy pass criteria for each brick type
    - Renumber routing, reset, and reliability phases
2026-04-10 docs(cad): update CAD architecture references for dual-ToF sizing
    - Replace beam-mount with dual-ToF sightline language
    - Update chamber sensing fit print gates and tolerances
    - Clarify ToF sightline preservation in sensor mount specs
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2026-04-11 docs(project): simplify states sorter architecture
    Center the active build on manual feed, conveyor sensing, and servo chute routing.
    Remove superseded custom conveyor and simulator work from the active tree.
    Update the firmware contract for the states routing flow.
    [Solenoid_0530.stl, Stepper Motor 17HS4401S.STEP, bearing_block.scad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]
2026-04-11 docs(project): clarify component reference library
    [2-star horn.SLDPRT, 4-star horn.SLDPRT, 6-star horn.SLDPRT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]
2026-04-11 docs(project): organize component reference assets
    [2_star_horn.sldprt, 4_star_horn.sldprt, 6_star_horn.sldprt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]
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2026-04-12 docs(project): consolidate sensing into single shrouded belt station
    - Color sensor and break beams merged into one printed tunnel at the feed end
    - Side rail guide centers brick before shroud entry; exit lip replaces flat stop wall
    - Eliminates separate mid-belt bracket and break beam clip components
2026-04-12 docs(conveyor): defer side rail guide to open decisions
    Removes Component 10 (side rail guide) from the build guide and CAD plan.
    The sensing shroud entry chamfer handles minor misalignment. Add only if
    real-brick testing shows a centering problem.
2026-04-12 docs(chute): lock in UHMW lining, short arm, and wide bin funnels as reliability strategy
    Three-layer approach removes angle sensitivity and servo precision as risks:
    UHMW-lined channel, arm under 100mm, funnel entries on all four bins.
    Also removes stale side rail guide reference from ARCHITECTURE.md.
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2026-04-12 docs(project): align states CAD handoff
    - Correct selector geometry guidance around Z stack, sweep radius, and funnel overlap
    - Add visual handoff diagrams for the chute selector
    - Sync break-beam sensing and conveyor build guidance
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2026-04-13 docs(project): clarify conveyor assembly clearances
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2026-04-14 docs(cad): align conveyor frame packaging
    Switches active frame guidance to a low base and side-panel motor mount. Adds checks for chute handoff height, GT2 access, and motor clearance.
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2026-04-14 docs(cad): simplify low conveyor frame
    Replace duplicate side-panel guidance with short base cleats and local motor reinforcement only where testing proves it is needed.
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2026-04-18 docs: align conveyor motor board direction and belt height across docs
    Previous docs described the NEMA17 as shaft-outward through the side plate.
    Active build uses an outside motor board with the shaft pointing inward.
    Updated ARCHITECTURE, CONVEYOR_BUILD_GUIDE, EQUATIONS, and reference docs.
    Belt surface height updated from 68mm to 72mm to match current CAD.
    [nsk_mr85zz.stp]
2026-04-18 docs(cad): record motor mount redesign and conveyor height open decision
    Motor mount is now a 2-stage L bracket with gussets on motor and frame sides.
    Center belt support extended to contact both side plates, enabling screws from outside.
    Pulley Y alignment documented: motor pulley at shaft tip, driven pulley against holder with 2mm spacer.
    Conveyor cleat height flagged as OPEN_DECISION gated on teammate's servo chute geometry.
    Motor board Z position and L bracket feet dimensions must not be finalized until height is confirmed.
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2026-04-18 docs(build): update assembly and test docs for 2-stage L bracket motor mount
    Replaced old motor board bracing language with the actual 2-stage L bracket
    with gussets on motor and frame sides. Updated pulley alignment steps to match
    current CAD: motor pulley at shaft tip, driven pulley with 2mm spacer.
2026-04-18 docs: fix stale docs and sensing shroud width note
    Corrected wrong sensing shroud width concern: the 25mm belt runs through the
    open bottom of the shroud and does not add to the horizontal brick clearance.
    30mm inner width is correct for the 15.8mm brick with adequate yaw margin.
    Added build status section to CONVEYOR_BUILD_GUIDE with sprint modifications.
    Replaced stale motor mount language throughout. Added *.log to gitignore for
    future session files.
2026-04-18 fix(states): align bin routing and sensing baseline
    Sync firmware routing and counts to the active bin order and break-beam decision.
    Tighten docs so height-dependent motor-board references stay derived, not fixed.
    [actuators.cpp, config.h, sensors.h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]
2026-04-18 docs(conveyor): standardize fixed-foot setup and lock guidance
    Use printed dual-stage bracket language consistently
    Set short slot holes on gusseted feet as the setup default before final lock-down
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2026-04-22 docs(cad): reflect sweep-defined bin arc in design docs
    - Prioritize servo placement and chute geometry as bin arc drivers
    - Add slotted servo feet for physical alignment tuning
    - Replace funnel concept with sweep-defined arc and locator platform
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2026-04-25 docs(sprint): replace stale CAD sprint plan with Apr 25 print-and-assemble sprint
    CAD is largely done. SHORT_TODO.md now reflects the active print queue, drill jig
    requirement, and assembly sequence for getting the conveyor spinning this weekend.
2026-04-25 docs(project): organize print workflow and reference notes
    - Define a cleaner active, deferred, staging, and archive layout for print exports
    - Refresh sprint build notes around electronics mounting and queue priorities
    - Simplify commit message guidance and add the LEGO 2x3 reference export
    [lego2x3_red.stp]
2026-04-25 fix(firmware): use timed handoff confirmation
    [config.h, state_machine.cpp, test_harness.cpp]
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2026-05-07 Clean up public OSS docs
    [acp4020_fan.ipt, acp4020_fan.step, tcs3200_color_sensor_module.stl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]
2026-05-08 fix: correct physical bin assignment order
    [actuators.cpp, config.h, state_machine.cpp]
2026-05-08 fix(firmware): recalibrate servo chute angles
    [config.h]
2026-05-08 fix(firmware): invert conveyor step direction polarity
    [config.h]
2026-05-08 fix(firmware): reduce slow-phase conveyor speed across all profiles
    [config.h]
2026-05-08 fix(firmware): require more color samples per sensing pass
    [config.h]
2026-05-08 fix(firmware): disable sensing retry on uncertain classification
    [config.h]
2026-05-08 fix(firmware): initialize servo to center position at startup
    [actuators.cpp]
2026-05-08 fix(firmware): guard conveyor PWM channel against double-attach
    [actuators.cpp]
2026-05-08 fix(simulation): update default belt speed to match measured value
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2026-09-01 docs(readme): replace ASCII flows with prose descriptions
    Replace arrow-based data flow diagrams with natural language descriptions:
    - Brick path through conveyor, sensors, and classification now in prose
    - System state sequence (FEED → SENSING → ROUTING → HANDOFF → CONFIRM)
    now described as clear transitions rather than ASCII arrows
    Improves readability for both technical and recruiter audiences while
    maintaining technical accuracy and conciseness.
2026-09-01 docs(readme): tighten mechanical design prose

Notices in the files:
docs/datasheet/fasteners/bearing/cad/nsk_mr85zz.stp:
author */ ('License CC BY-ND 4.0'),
